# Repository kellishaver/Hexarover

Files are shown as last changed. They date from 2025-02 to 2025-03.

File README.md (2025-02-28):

Project Hexarover: A Modular Environmental Sensing Platform
====

Hexarover is a modular robotic platform designed for environmental sensing and exploration. At its core, it combines sophisticated hardware integration with versatile software architecture to create a highly adaptable rover system.

Key Features:
---

* **Modular Sensor Architecture:** The universal mounting system enables quick swapping of sensor modules without tools, allowing for mission-specific configurations

* **Thoughtful Physical Design:** The carefully planned component layout balances cooling, structural integrity, and accessibility

* **Wireless Control Interface:** Leverages ESP32-CAM WiFi capabilities for both camera streaming and vehicle control through a unified web interface

* **Advanced Power Management:** A purpose-built power distribution system with voltage regulation and monitoring

* **API-Driven Development:** RESTful API implementation enables sensor data collection and integration with external visualization dashboards

* **Open Source Foundation:** Designed with complete documentation and shareable STL files to encourage community contributions and extensions

* **3D-Printable Construction:** All custom components designed for optimal printability, with consideration for material properties and minimal support requirements

Technical Implementation:
----

The project combines Arduino-based control systems with ESP32 wireless connectivity, creating a platform that can be easily extended through both hardware additions and software updates. The thoughtful separation of concerns between physical mobility, environmental sensing, and data processing creates a robust foundation for ongoing development.

Hexarover represents a unique intersection of robotics, environmental science, and IoT technology - all built with accessibility and customization as core design principles.

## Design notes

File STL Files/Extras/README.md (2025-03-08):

Extras
====

Bumper
----

To mount the bumper to the Rover's front and/or rear side panels, please measure and attach two half-size universal mounting brackets to those panels. The top mount is integrated into the bumper design.

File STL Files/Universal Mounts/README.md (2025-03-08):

Universal Mounting Bracket
====

These pieces are designed with very tight tolerances and material shrinkage can vary. It is very likely that you will find that the top and bottom halves of the mount slide together much more snugly than desired. While it's possible to scale down the top piece of the bracket, I personally found it more reliable to print at the provided size and then do light sanding on the top piece as-needed.

Also, note that the dovetail joint will loosen very slightly over time, so take care not to remove too much material. 

The TPU Band fit should be snug, but not so tight that removing it risks breaking the band.

It is recommended not to run the rover without the bands in place, as this can cause mounted parts to loosen over time due to vibration, potentially resulting in damage to the sensor unit.

An optional TPU vibrationd dampener is also provided and can be placed between the mount's base and the top chassis, should you want to mount particularly sensetive parts.

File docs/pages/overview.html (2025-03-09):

# Project Hexarover

A Modular Environmental Sensing Platform

## Overview

Hexraover is a modular environmental sensing rover with these key technical components:

- Core Platform: Arduino Uno controlling 4 TT motors via L298N motor drivers, powered by dual 18650 batteries (5000mAh) with voltage regulation through a DC-DC buck converter
- Communication System: ESP32-CAM modules providing WiFi connectivity, video streaming, and REST API endpoints for remote control and data access
- Distributed Computing Architecture: Each sensor pack will have its own Arduino Nano microcontroller, communicating with the main Arduino via I2C protocol
- Modular Hardware Design: Custom 3D printed chassis with a Universal Mounting Bracket (UMB) system for tool-free swapping of sensor modules
- Sensor Categories:
  - Atmospheric monitoring (temperature, humidity, pressure, etc.)
  - Terrain analysis (soil moisture, vibration, inclination)
  - Navigation awareness (ultrasonic, infrared, obstacle detection)
- Software Framework: Web interface for control and data visualization, with a REST API enabling configuration of which sensors are connected to which pins
- Mechanical Features: Hybrid PLA/TPU wheel design with 3D printed cores and flexible TPU tires for better traction

The project emphasizes modularity throughout - both physically through the universal mounting system and electronically through the distributed microcontroller approach. This allows for customization and incremental development while maintaining a clean separation of concerns in the code.

### Hexarover's Story

Hexarover began as a small idea that evolved into something much larger and much more meaningful. My goal for this project is to create an accessible, reasonably affordable, open platform for exploration, fun, and learning. Seeing Hexarover show up in someone's school robotics program or STEM learning camp, or simply hearing of other people enjoying the project would be a dream come true for a very special reason.

This rover is the type of project my father and I would have undertaken together when I was a young teen. He was always making, repairing, building, and creating and he had a fondness for electronics and technology. He instilled this curiosity and creativity in me and I credit it for much joy and the success I've had in my life.

I'm a woman who was born blind in the 70s and grew up poor. I doubt anyone expected me to go into a STEM field. But my father never let cultural expectations or my own supposed limitations get in the way of helping me pursue my interests.

This project is a tribute to that spirit and that dedication.

« Table of Contents

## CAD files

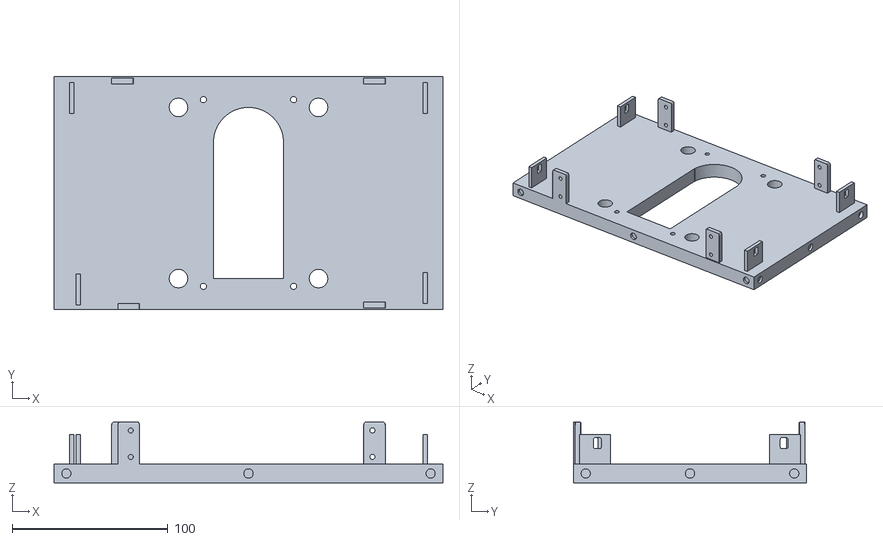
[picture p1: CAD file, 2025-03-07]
STL Files/Chassis/Bottom Plate.stl
250.0 x 150.0 x 39.0

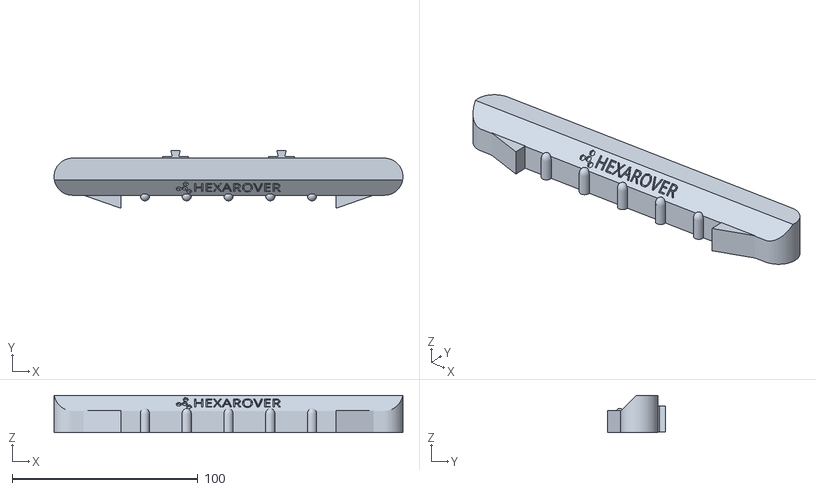
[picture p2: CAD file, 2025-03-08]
STL Files/Extras/Bumper (TPU).stl
188.0 x 31.0 x 20.0

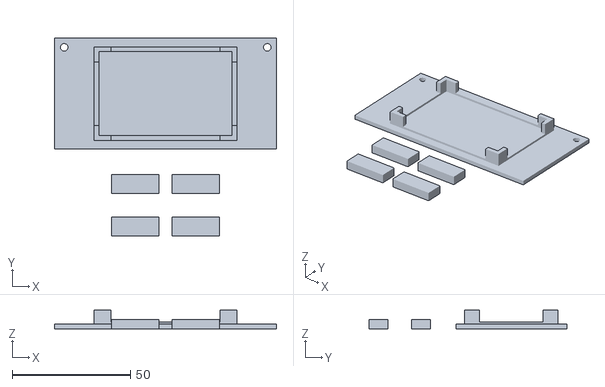
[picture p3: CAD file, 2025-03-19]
STL Files/Fixed Mounts/PDS - Top.stl
94.0 x 83.7 x 8.00

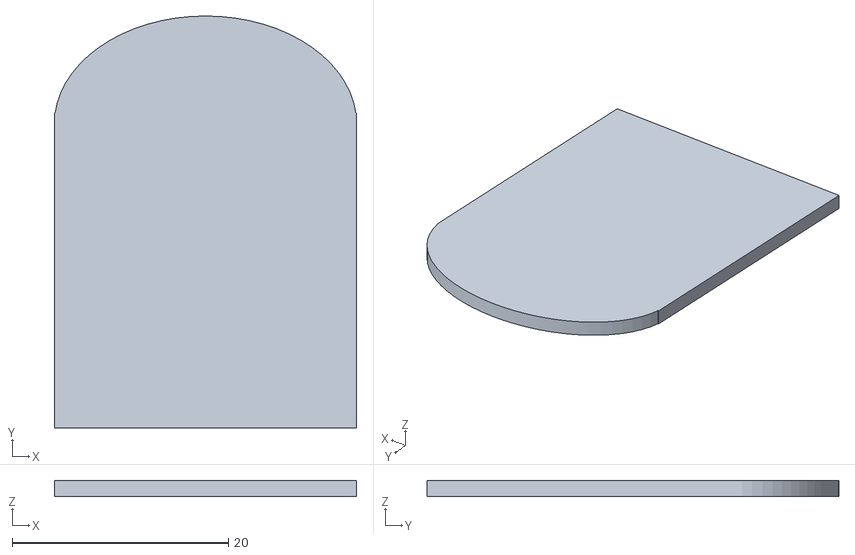
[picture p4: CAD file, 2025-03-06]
STL Files/Universal Mounts/UMB - Vibration Dampener (TPU).stl
28.0 x 38.1 x 1.50

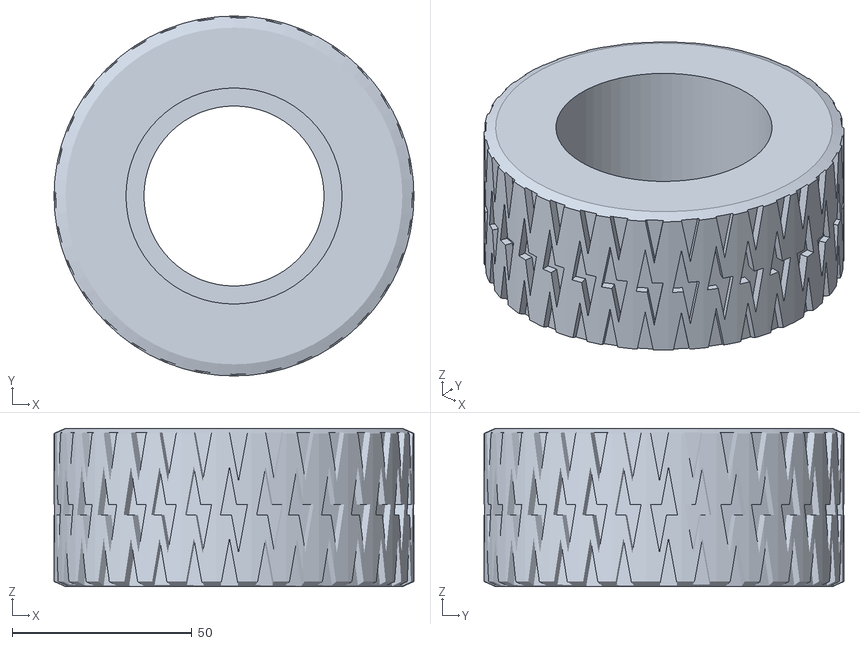
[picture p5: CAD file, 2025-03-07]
STL Files/Wheels/Tire (TPU).stl
100.0 x 100.0 x 44.0

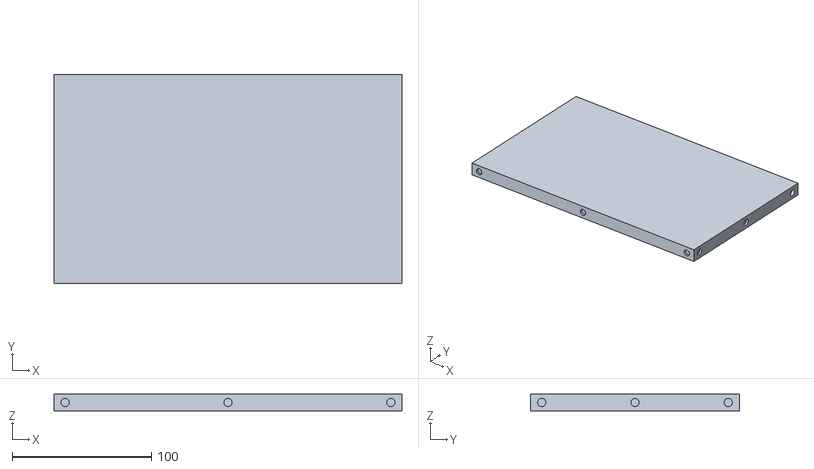
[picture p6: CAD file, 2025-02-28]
STL Files/Chassis/Blank Top Plate.stl
250.0 x 150.0 x 12.0

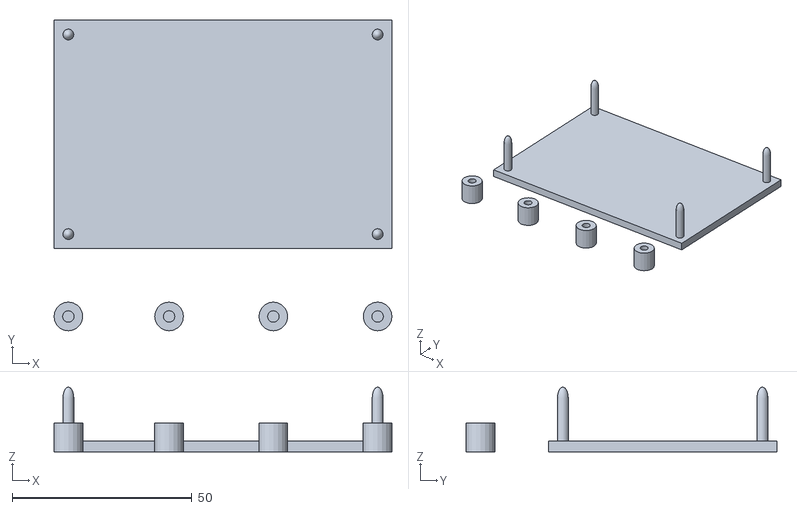
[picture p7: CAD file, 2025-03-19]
STL Files/Fixed Mounts/PDS - Base.stl
94.0 x 86.4 x 18.0

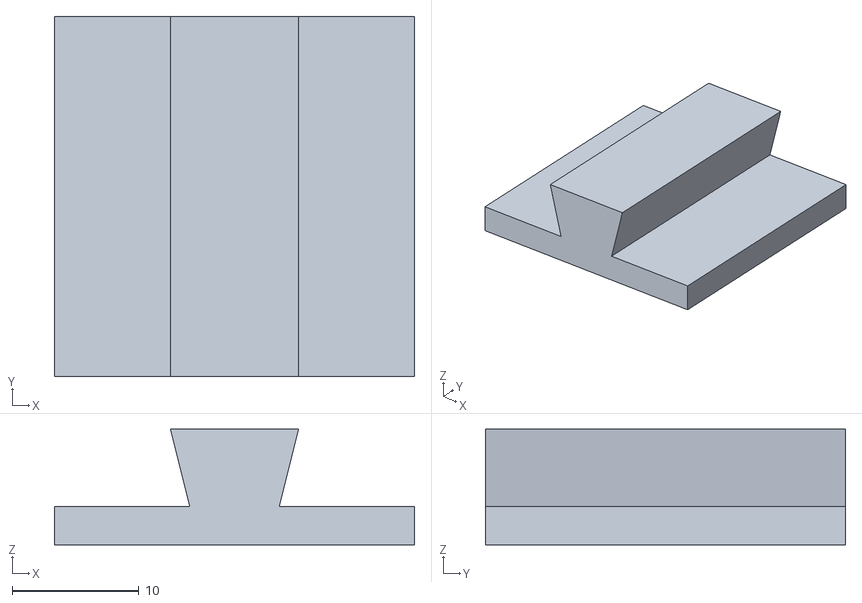
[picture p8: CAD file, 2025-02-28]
STL Files/Universal Mounts/UMB - Top.stl
28.4 x 28.4 x 9.13

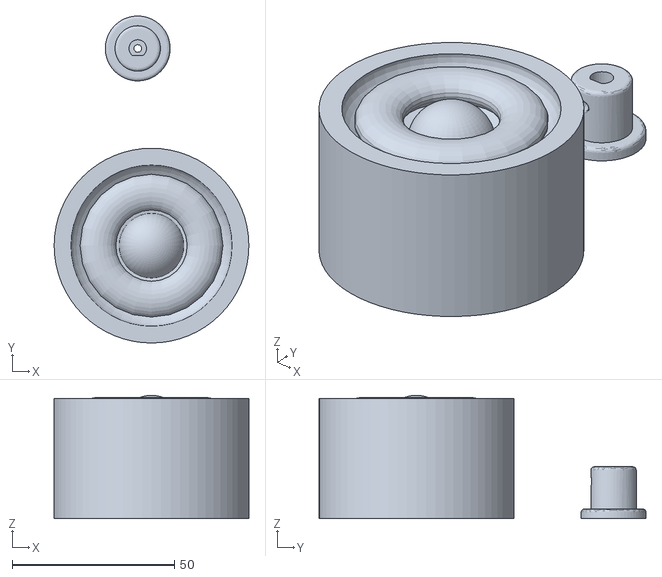
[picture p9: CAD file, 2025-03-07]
STL Files/Wheels/Wheel.stl
60.0 x 100.7 x 38.0

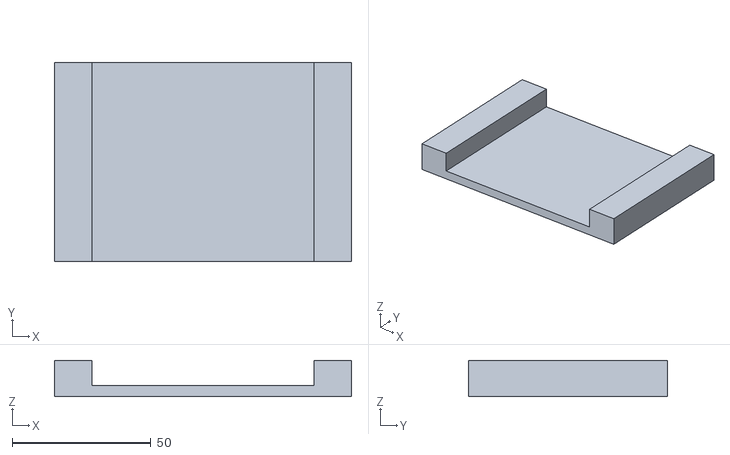
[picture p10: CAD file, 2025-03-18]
STL Files/Fixed Mounts/Uno Plate Riser.stl
107.0 x 71.6 x 13.0

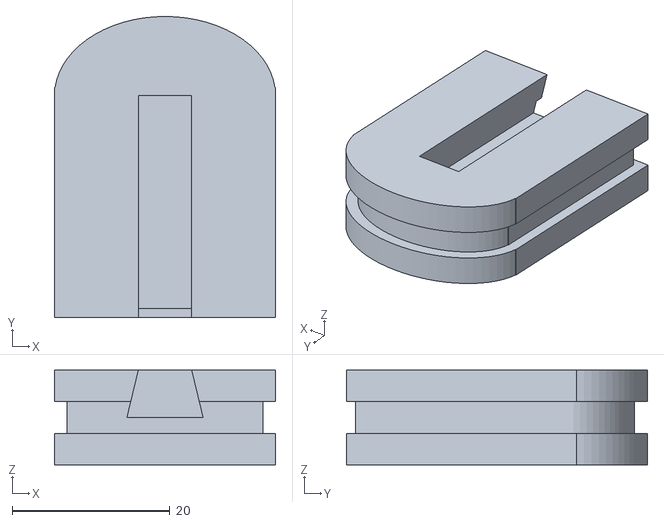
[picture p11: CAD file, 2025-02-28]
STL Files/Universal Mounts/UMB - Base.stl
28.0 x 38.1 x 12.0

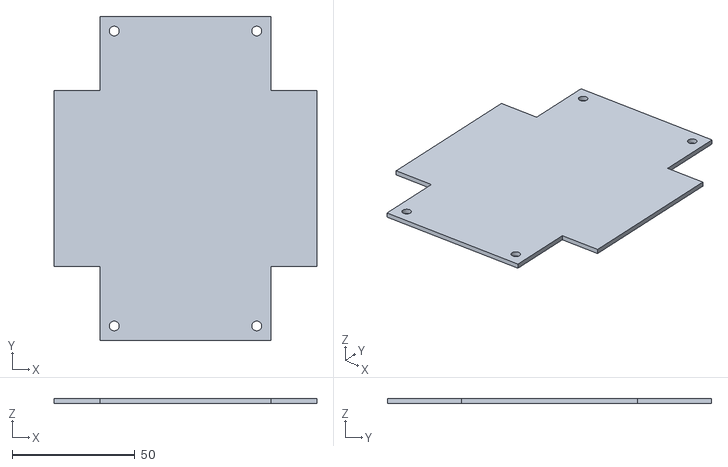
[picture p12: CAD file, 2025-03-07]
STL Files/Fixed Mounts/Battery Box Mount Plate.stl
107.0 x 132.0 x 2.00

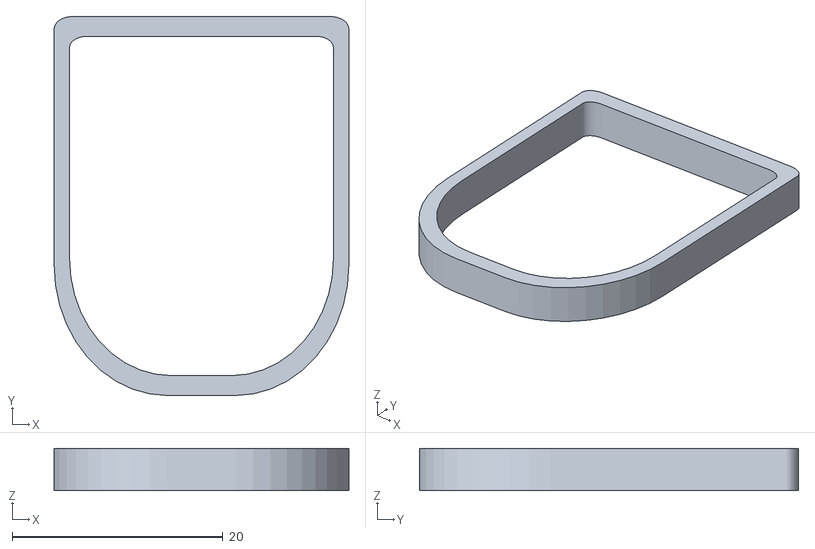
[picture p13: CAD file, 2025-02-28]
STL Files/Universal Mounts/UMB - Tension Band (TPU).stl
28.0 x 36.0 x 4.00

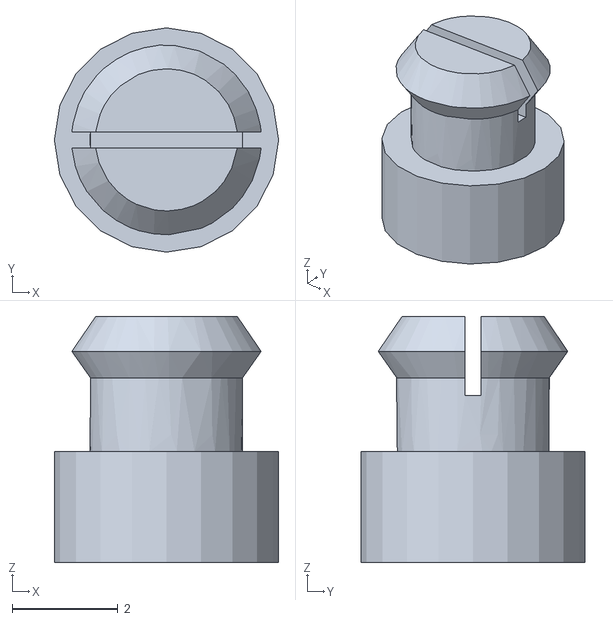
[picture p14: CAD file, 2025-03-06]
STL Files/Fixed Mounts/PCB Mounting Stud.stl
4.25 x 4.25 x 4.66

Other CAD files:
STL Files/Fixed Mounts/Uno Mount Plate.stl

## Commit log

2025-02-28 Adding some STLs and readme
    [Blank Top Plate.stl, Bottom Plate.stl, UMB - Base.stl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]
2025-02-28 properly scaled top UMB
    [UMB - Top.stl]
2025-03-06 adding readme for UMB and generic mounting stud STL
    [PCB Mounting Stud.stl]
2025-03-06 adding TPU vibration dampener for UMB and updating readme
    [UMB - Vibration Dampener (TPU).stl]
2025-03-07 Bottom plate rev1, battery box mount plate, Uno riser, wheel and tire v1
    [Battery Box Mount Plate.stl, Bottom Plate.stl, Tire (TPU).stl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]
2025-03-08 updating docs
    [Bumper (TPU).stl]
2025-03-09 updating docs and adding the PDS shield
    [PDS - Base.stl, PDS - Top.stl]
2025-03-09 updating PDS base STL with longer studs to account for solder joints on the breadboard
    [PDS - Base.stl]
2025-03-18 updating some STLs, diagrams, and parts list
    [Uno Plate Riser.stl]
2025-03-19 updating some fixed mounts
    [PDS - Base.stl, PDS - Top.stl]
